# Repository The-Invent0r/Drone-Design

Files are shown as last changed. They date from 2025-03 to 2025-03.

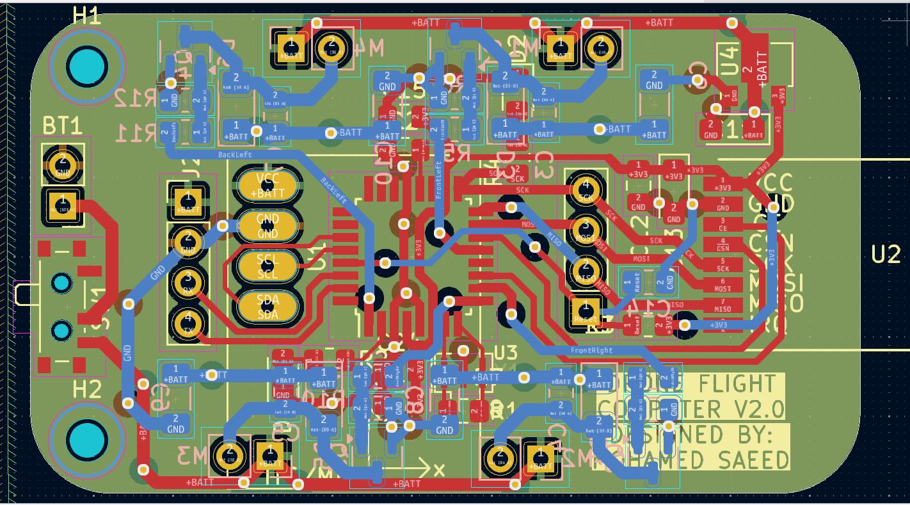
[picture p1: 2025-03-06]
Hardware/Flight Controller Schematics/PCB.JPG

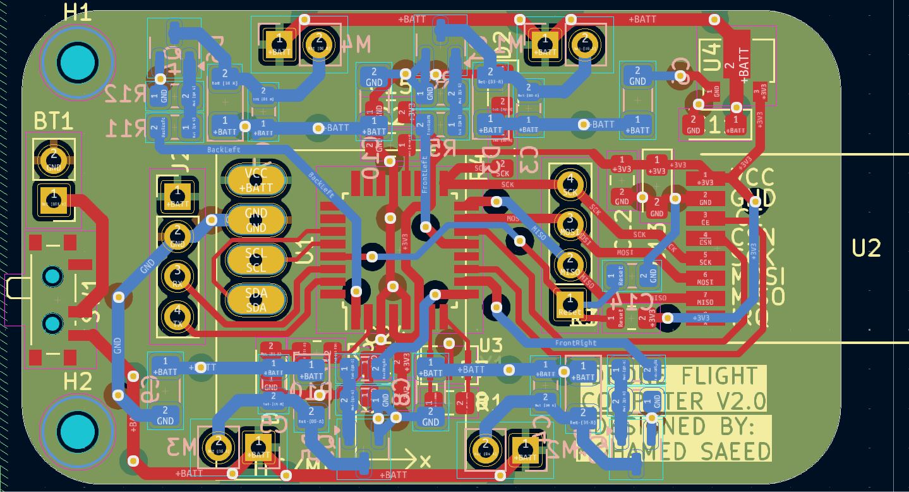
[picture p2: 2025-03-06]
Hardware/Flight Controller Schematics/PCB HD.JPG

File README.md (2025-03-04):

# Custom Drone flight controller PCB and radio controller + all software.

## Overview
This is a custom flight controller I designed and built for a brushed DC motor drone, powered by an ATmega328p microcontroller, nRF24l01 radio, and MPU6050 IMU. I wanted a hands-on challenge to merge my skills in PCB design, microcontrollers, and motor control—after a year of troubleshooting, it flies stable and takes wireless commands.

## Features
- Real-time stabilization using MPU6050 gyro and accelerometer data.  
- Wireless control via nRF24l01 at 2.4GHz.  
- Drives four brushed DC motors with custom MOSFET-based drivers.  
- Lightweight 4-layer PCB with EMI shielding and efficient power distribution.

## Design & Build
- **Hardware**:  
  - *ATmega328p*: Familiar, handles PWM, I2C, and SPI for motors, IMU, and radio. Runs at 3.7V (LiPo)—tested stable at 16MHz, no boost converter needed.  
  - *MPU6050*: 3-axis gyro and accelerometer for flight dynamics.  
  - *nRF24l01*: 2.4GHz radio for ground station comms.  
  - *IRLML2502 MOSFETs*: Low Rds, fast-switching drivers for four motors, with Schottky flyback diodes.  
  - *1S 90C LiPo*: Powers it all; ditched regulators after testing.  
- **PCB**: Started with a 2-layer board, but motor EMI kept resetting the MCU. Switched to a 4-layer design—motor drivers on bottom, sensitive components on top, ground/power planes in between for shielding, I also tried a 6-layer board which worked just as well as the 4-layer board.
- **Tools**: KiCAD for schematics and PCB layout, soldering iron and heat gun for assembly, Multiwii open-source software for fast firmware.  
- **Challenges**:  
  - EMI from motors crashed the MCU. Tried a 5V boost converter—didn’t help. Went 3.7V direct from LiPo, still issues.  
  - 4-layer and 6-layer PCB rethink separated high-current and signal paths—killed the resets.

## Results
Breadboard tests nailed stable motor control; bench sims proved IMU-driven stabilization. It’s rough but works—tweaking PWM is next for smoother flight.

## Media
4-layer board



go2-2u-r
JmDARRze

6-layer board

5ym9NuEH
L8ePkmEb

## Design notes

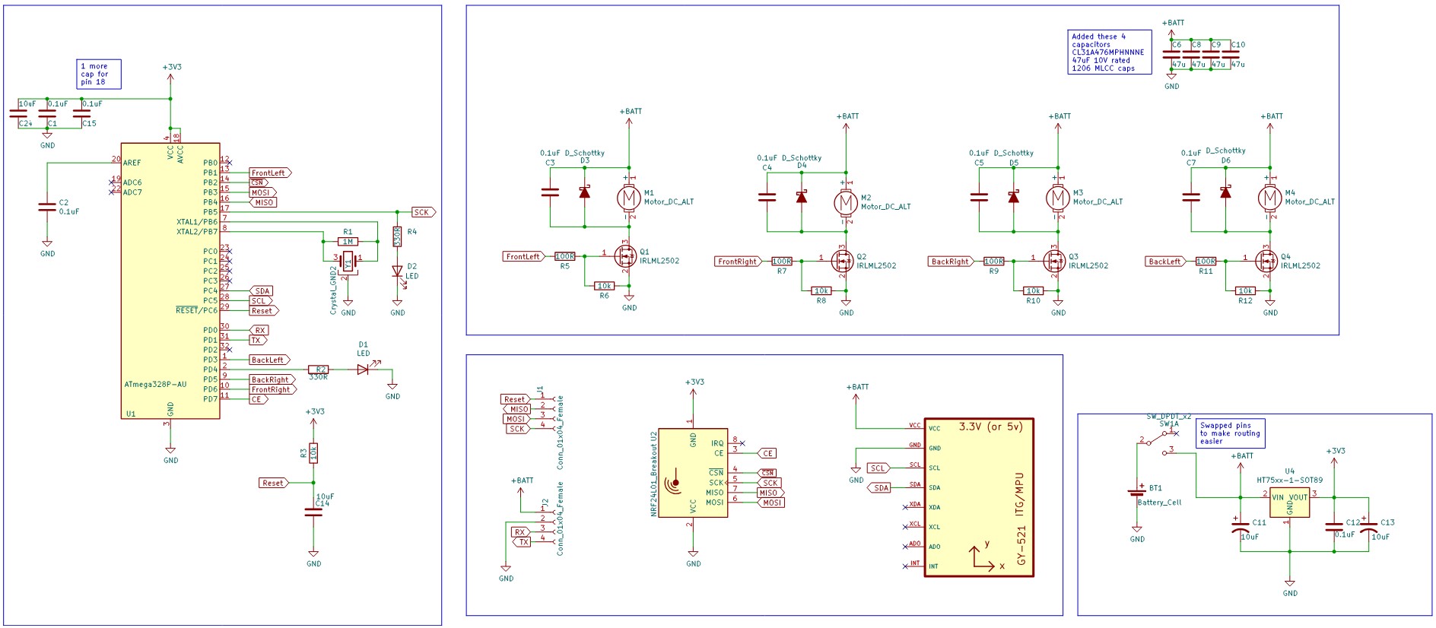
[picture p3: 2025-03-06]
Hardware/Flight Controller Schematics/SCHEMATIC.jpg

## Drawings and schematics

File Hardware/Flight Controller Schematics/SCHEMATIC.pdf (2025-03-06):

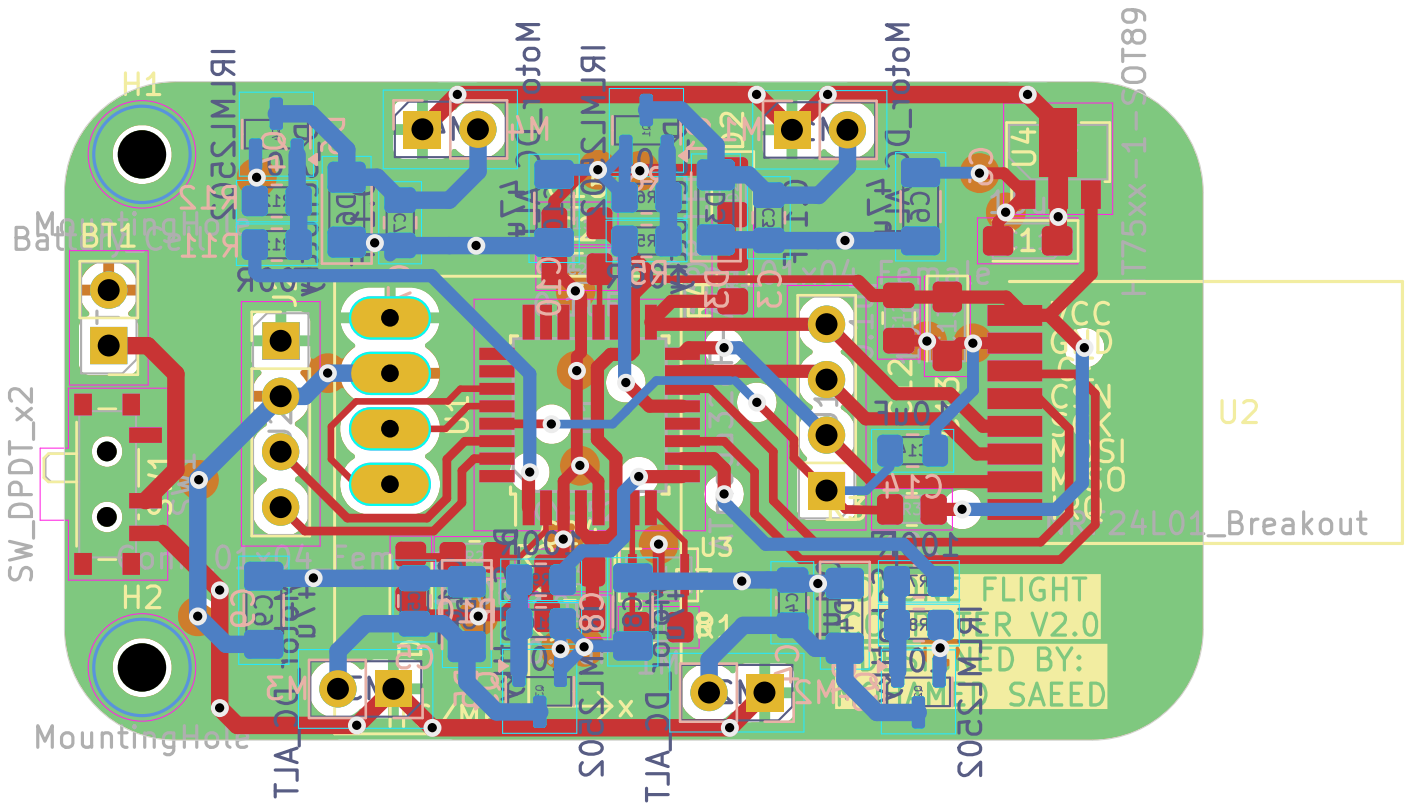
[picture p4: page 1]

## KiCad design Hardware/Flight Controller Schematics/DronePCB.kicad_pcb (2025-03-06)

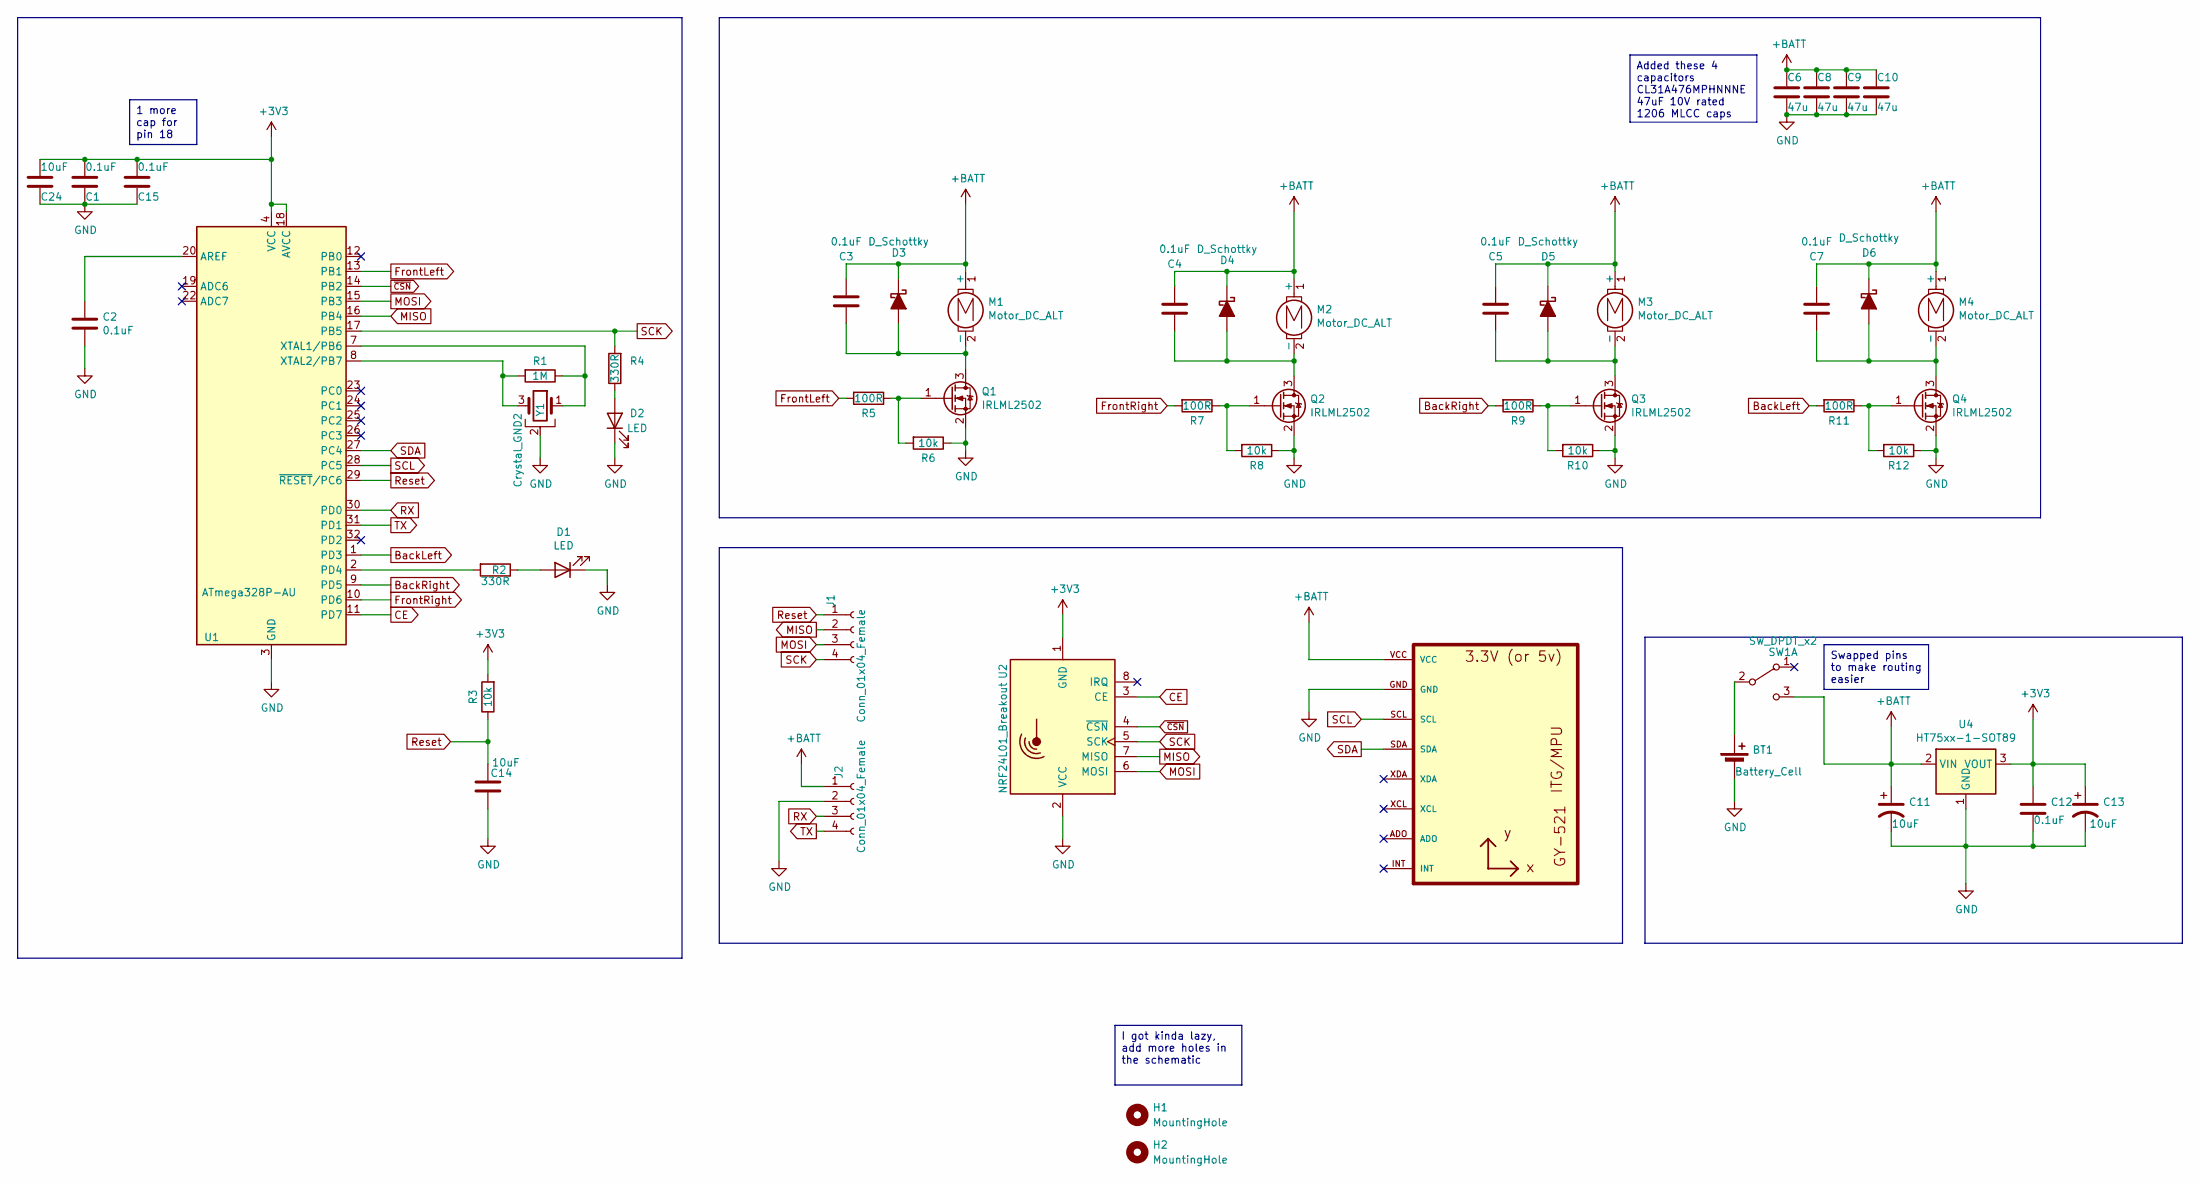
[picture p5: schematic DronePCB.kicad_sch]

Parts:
BT1: Battery_Cell; PinHeader_1x02_P2.54mm_Vertical
C1, C2, C3, C4, C5, C7, C12, C15: 0.1uF; C_0805_2012Metric_Pad1.18x1.45mm_HandSolder
C6, C8, C9, C10: 47u; C_1206_3216Metric_Pad1.33x1.80mm_HandSolder
C11, C13: 10uF; CP_EIA-3216-10_Kemet-I
C14, C24: 10uF; C_0805_2012Metric_Pad1.18x1.45mm_HandSolder
D1, D2: LED; LED_0805_2012Metric_Pad1.15x1.40mm_HandSolder
D3, D4, D5, D6: D_Schottky; D_1206_3216Metric_Pad1.42x1.75mm_HandSolder
H1, H2: MountingHole; MountingHole_2.2mm_M2
J1, J2: Conn_01x04_Female; PinHeader_1x04_P2.54mm_Vertical
M1, M2, M3, M4: Motor_DC_ALT; PinHeader_1x02_P2.54mm_Vertical
Q1, Q2, Q3, Q4: IRLML2502; SOT-23
R1: 1M; R_0805_2012Metric_Pad1.20x1.40mm_HandSolder
R2, R4: 330R; R_0805_2012Metric_Pad1.20x1.40mm_HandSolder
R3, R6, R8, R10, R12: 10k; R_0805_2012Metric_Pad1.20x1.40mm_HandSolder
R5, R7, R9, R11: 100R; R_0805_2012Metric_Pad1.20x1.40mm_HandSolder
SW1: SW_DPDT_x2; SW_SPDT_PCM12
U1: ATmega328P-AU; TQFP-32_7x7mm_P0.8mm
U2: NRF24L01_Breakout; NRF24L01-Module-SMD
U3: GY-521
U4: HT75xx-1-SOT89; SOT-89-3
Y1: Crystal_GND2; Resonator_SMD_muRata_CSTxExxV-3Pin_3.0x1.1mm

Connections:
+3V3: C1.2, C12.1, C13.1, C15.2, C24.2, R3.2, U1.4 (VCC), U1.6 (VCC), U1.18 (AVCC), U2.1 (GND), U4.3 (VOUT)
+BATT: C3.1, C4.1, C5.1, C6.1, C7.1, C8.1, C9.1, C10.1, C11.1, D3.1 (K), D4.1 (K), D5.1 (K), D6.1 (K), J2.1, M1.1 (+), M2.1 (+), M3.1 (+), M4.1 (+), SW1.3 (C), U3.VCC, U4.2 (VIN)
BackLeft: R11.2, U1.1 (PD3)
BackRight: R9.2, U1.9 (PD5)
CE: U1.11 (PD7), U2.3 (CE)
FrontLeft: R5.2, U1.13 (PB1)
FrontRight: R7.2, U1.10 (PD6)
GND: BT1.2 (-), C1.1, C2.2, C6.2, C8.2, C9.2, C10.2, C11.2, C12.2, C13.2, C14.2, C15.1, C24.1, D1.1 (K), D2.1 (K), J2.2, Q1.2 (S), Q2.2 (S), Q3.2 (S), Q4.2 (S), R6.1, R8.1, R10.1, R12.1, U1.3 (GND), U1.5 (GND), U1.21 (GND), U2.2 (VCC), U3.GND, U4.1 (GND), Y1.2
MISO: J1.2, U1.16 (PB4), U2.7 (MISO)
MOSI: J1.3, U1.15 (PB3), U2.6 (MOSI)
unnamed: BT1.1 (+), SW1.2 (B)
unnamed: D1.2 (A), R2.1
unnamed: D2.2 (A), R4.1
unnamed: C3.2, D3.2 (A), M1.2 (-), Q1.3 (D)
unnamed: C4.2, D4.2 (A), M2.2 (-), Q2.3 (D)
unnamed: C5.2, D5.2 (A), M3.2 (-), Q3.3 (D)
unnamed: C7.2, D6.2 (A), M4.2 (-), Q4.3 (D)
unnamed: Q1.1 (G), R5.1, R6.2
unnamed: Q2.1 (G), R7.1, R8.2
unnamed: Q3.1 (G), R9.1, R10.2
unnamed: Q4.1 (G), R11.1, R12.2
unnamed: C2.1, U1.20 (AREF)
unnamed: R2.2, U1.2 (PD4)
unnamed: R1.1, U1.7 (XTAL1/PB6), Y1.1
unnamed: R1.2, U1.8 (XTAL2/PB7), Y1.3
RX: J2.3, U1.30 (PD0)
Reset: C14.1, J1.1, R3.1, U1.29 (~RESET/PC6)
SCK: J1.4, R4.2, U1.17 (PB5), U2.5 (SCK)
SCL: U1.28 (PC5), U3.SCL
SDA: U1.27 (PC4), U3.SDA
TX: J2.4, U1.31 (PD1)
~CSN: U1.14 (PB2), U2.4 (~CSN)

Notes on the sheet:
1 more cap for pin 18
Added these 4 capacitors CL31A476MPHNNNE 47uF 10V rated 1206 MLCC caps
Swapped pins to make routing easier
I got kinda lazy, add more holes in the schematic

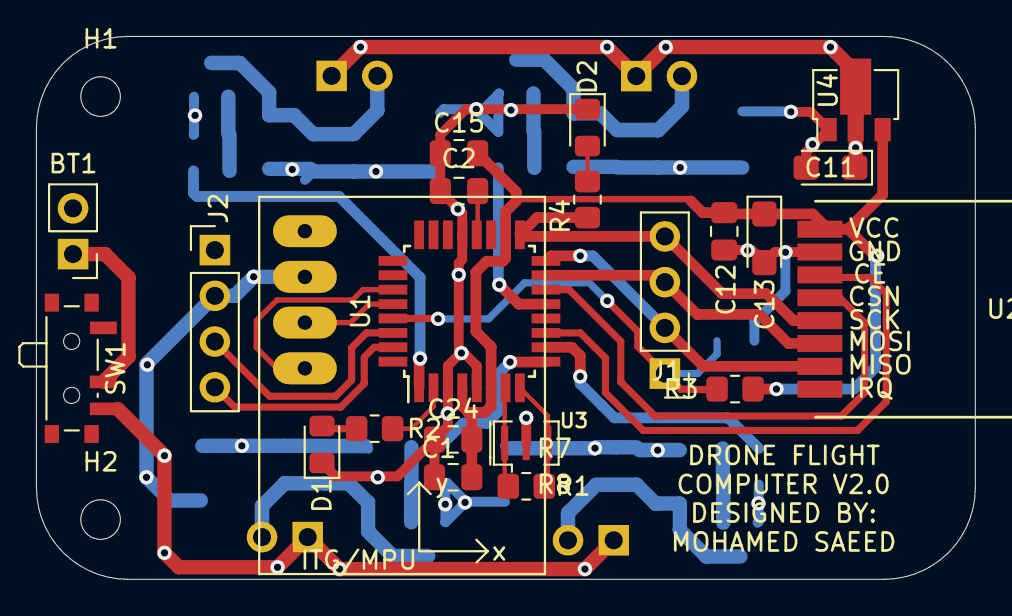
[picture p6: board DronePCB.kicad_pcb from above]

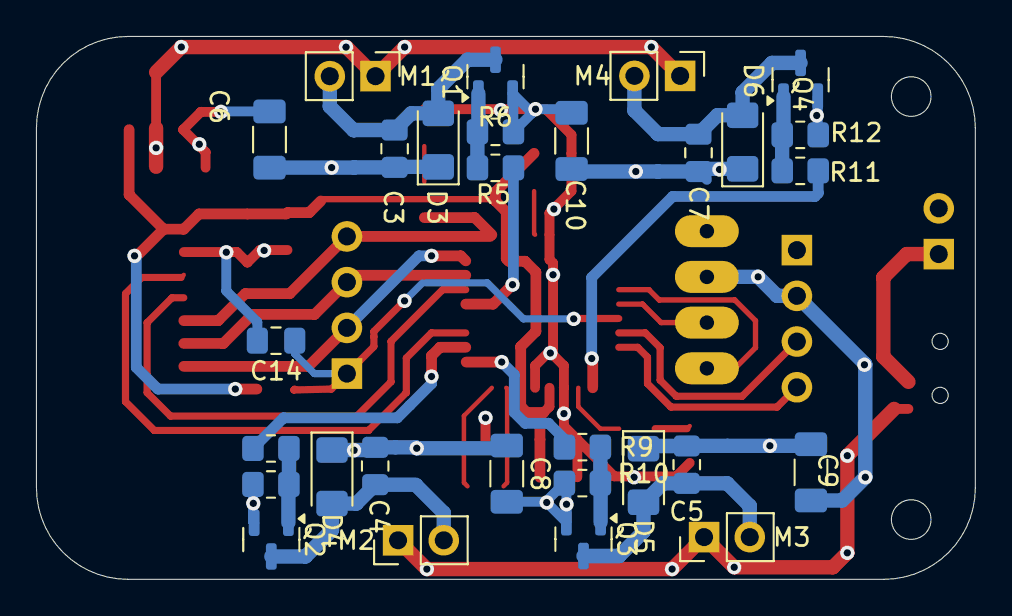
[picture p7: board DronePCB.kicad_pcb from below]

Board: 4 copper layers, 52.2 x 30.2 mm, 53 parts (29 on the bottom side), 32 nets.

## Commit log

2025-03-04 Create Readme
    flight controller schematics and files
2025-03-04 Create Readme
    remote control schematic and files
2025-03-06 Create Flight Controller Schematics
    flight controller hardware schematics
2025-03-06 Create Readme
    flight controller schematics
2025-03-06 Create Readme
    remote controller schematics
